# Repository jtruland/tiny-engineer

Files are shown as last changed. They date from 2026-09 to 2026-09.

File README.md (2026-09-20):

# Tiny Engineer

> Give your AI coding agent a body.

Tiny Engineer demo

Tiny Engineer is an open-source, 3D-printable desktop robot that physically acts out what an AI coding agent is doing: reading, thinking, coding, finishing tasks. It runs on an ESP32 over Wi-Fi and exposes a simple REST API, so any tool that can make an HTTP request can drive it.

**[Watch the demo](https://youtu.be/RX_QRxdXMjg) · [Build your own](#build-your-own) · [How it works](#how-it-works) · [API](docs/api.md)**

## Why?

AI coding agents increasingly spend long stretches working on their own. I wanted to see what mine was doing without staring at the IDE.

So I built a slightly ridiculous desk robot: instead of another spinner or status line, there is a tiny teammate sitting next to me, visibly reading, thinking, and typing while the agent works.

## How it works

How Tiny Engineer works

An AI agent works; an integration turns that into events; the robot’s REST API on your LAN receives them; the hardware moves and reacts.

**How it connects**

- **Cursor** — Cursor Agent → Cursor hooks → `tiny-engineer-cursor` → HTTP over Wi-Fi
- **Antigravity CLI** — Antigravity Agent → lifecycle hooks → `tiny-engineer-antigravity` → HTTP over Wi-Fi
- **Bring your own** — Claude, Codex, or any other agent → your script/plugin/app → HTTP REST

Both hit the same Tiny Engineer REST API (`/anim`). The ESP32-C3 runs that API, robot logic, and animations, then drives:

| Bus | Hardware | Role |
| --- | --- | --- |
| I2C | PCA9685 → 5× servos | Head / neck, hands / body |
| I2C | Waveshare 0.91inch OLED (SSD1306) | Status, face, info |
| I2S | MAX98357A → speaker | Audio |

Cursor is one, sample, client, not the architecture. Details: [Cursor hooks](docs/hooks.md) · [any integration](docs/integration.md) · [HTTP API](docs/api.md)

## Build your own

End-to-end path (details live in the linked docs):

New to hardware? Start with **[From Code to Circuits](docs/hardware-for-software-engineers/README.md)** — hardware and electronics for software engineers; Tiny Engineer is the worked example.

1. **Get the electronics** — [hardware inventory](docs/hardware/components.md)
2. **3D print the parts** — [printables](3d_models/README.md). Different servo size: [parametric CAD](docs/3d/parametric-design.md)
3. **Assemble the mechanics** — fit the five servos — [3D models](3d_models/README.md), [servo axes](docs/robot-movement.md)
4. **Wire the electronics** — [wiring](docs/hardware/wiring.md), [hardware overview](docs/hardware/README.md)
5. **Flash the ESP32 firmware** — [getting started → Flash](docs/getting-started.md#4-flash)
6. **Configure Wi-Fi** — [getting started → Wi-Fi](docs/getting-started.md#5-wi-fi-setup)
7. **Test the robot** — web UI + a curl — [getting started → Prove it](docs/getting-started.md#6-prove-it)
8. **Connect your coding agent** — [Cursor hooks](docs/hooks.md) or [any IDE / REST](docs/integration.md)

Full walkthrough: [docs/getting-started.md](docs/getting-started.md).

## Hardware overview

Major pieces (exact models and counts in the BOM):

| Role | Part | Qty |
| --- | --- | --- |
| Controller | Waveshare ESP32-C3-Zero | 1 |
| Servo PWM | Adafruit PCA9685 | 1 |
| Actuators | Analog micro servos — **Tower Pro SG90 recommended**; Feetech FS0307 for a compact build; PowerHD HD-1370A still supported | 5 |
| Display | [Waveshare 0.91inch OLED Module](https://www.waveshare.com/0.91inch-oled-module.htm) (SSD1306, 128×32, I2C) | 1 |
| Audio | MAX98357A + 8 Ω / 1 W speaker | 1 + 1 |
| USB / power | Adafruit 5993 USB-C breakout; **5 V / ≥2 A** supply | 1 |
| Structure | 3D-printed parts | — |

Complete inventory and limits: [docs/hardware/components.md](docs/hardware/components.md). Which servo to buy and which parts to print: [docs/3d/parametric-design.md](docs/3d/parametric-design.md).

## Quick start

Firmware is Arduino on [PlatformIO](https://platformio.org/). From the project root:

```bash
pio run                 # build
pio run -t upload       # flash firmware + LittleFS
pio device monitor      # serial (115200)
```

If servos move but audio is silent, run `pio run -t uploadfs` once.

**Wi-Fi (first boot):** join `TinyEngineer-XXXX`, open `http://192.168.4.1/config`. Wizard: servos, screen orientation, RGB LED, speaker, then a **2.4 GHz** network. OLED shows the join-AP steps.

**Web UI:** `http://tiny-engineer.local/` (or the IP on the OLED) — settings, hardware tests, animations.

**Make it move:**

```bash
curl -X POST "http://tiny-engineer.local/anim?name=ring"
```

Full route list: [docs/api.md](docs/api.md). Settings: [docs/settings.md](docs/settings.md).

## AI integrations

Anything that can `POST` over HTTP can drive the robot:

```bash
curl -X POST "http://tiny-engineer.local/anim?name=typing"
```

Useful `name` values: `typing`, `reading`, `thinking`, `ring`, `welcome`, `wakeup`, `sleep`, `attention`, `error`, `abort`, `dead`, `none`.

Cursor projects can map agent events to poses via hooks — [docs/hooks.md](docs/hooks.md). Broader patterns and examples: [docs/integration.md](docs/integration.md). Optional extra: sleep/wake when you lock or unlock a Mac — [docs/macos-lock-unlock.md](docs/macos-lock-unlock.md).

## Documentation

| Goal | Doc |
| --- | --- |
| Build end-to-end | [docs/getting-started.md](docs/getting-started.md) |
| Parts / BOM | [docs/hardware/components.md](docs/hardware/components.md) |
| Wiring / power | [docs/hardware/README.md](docs/hardware/README.md) |
| Printable parts | [3d_models/README.md](3d_models/README.md) |
| Resize CAD for another servo | [docs/3d/parametric-design.md](docs/3d/parametric-design.md) |
| Servo axes / safe ranges | [docs/robot-movement.md](docs/robot-movement.md) |
| HTTP API | [docs/api.md](docs/api.md) |
| Settings | [docs/settings.md](docs/settings.md) |
| Cursor hooks | [docs/hooks.md](docs/hooks.md) |
| Any IDE / REST | [docs/integration.md](docs/integration.md) |
| Firmware / package tests | [docs/testing.md](docs/testing.md) |
| Full index | [docs/README.md](docs/README.md) |

## Build one, break one, share it

Print it, wire it, change the CAD, swap animations, or hook up a different agent. Issues and PRs welcome — especially new integrations. See [CONTRIBUTING.md](CONTRIBUTING.md). Vulnerabilities: [SECURITY.md](SECURITY.md). Conduct: [CODE_OF_CONDUCT.md](CODE_OF_CONDUCT.md).

Tiny Engineer

## License

- **Software** (firmware, integrations, scripts, documentation) — [MIT](LICENSE)
- **Hardware designs** (CAD source and `.3mf` printables in [`3d_models/`](3d_models/); KiCad PCBs in [`hardware/`](hardware/)) — [CERN-OHL-S-2.0](3d_models/LICENSE)

See [LICENSING.md](LICENSING.md) for scope and effective date. The **Tiny Engineer** name and logo are not licensed — see [TRADEMARK.md](TRADEMARK.md).

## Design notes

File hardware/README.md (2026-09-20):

# Hardware (PCB)

KiCad PCB projects for Tiny Engineer.

Boards live under `boards/<board-name>/`. Prefer the same name for the directory and the KiCad project.

Contribution rules, KiCad version, what to commit, ERC/DRC, and PR expectations: [docs/pcb.md](../docs/pcb.md). Pre-PR checklist: [docs/pcb.md#checklist](../docs/pcb.md#checklist). Critical net checklist: [docs/pcb.md#expected-netsyml](../docs/pcb.md#expected-netsyml).

This tree is KiCad source only. Robot electrical reference (pinout, wiring, BOM) is [`docs/hardware/`](../docs/hardware/README.md). Firmware drivers are `src/hardware/`.

## License

Board sources in `boards/` are [CERN-OHL-S-2.0](LICENSE). See [NOTICE](NOTICE) for copyright, Source Location, and product notice requirements.

This README is software documentation and remains under the MIT License — [LICENSING.md](../LICENSING.md).

The **Tiny Engineer** name and logo are not licensed — [TRADEMARK.md](../TRADEMARK.md).

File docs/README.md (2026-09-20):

# Docs index

Pick a path. Depth lives in the linked pages.

| You want to… | Start here |
| --- | --- |
| **Bridge into hardware/electronics** (software engineer background) | [hardware-for-software-engineers/README.md](hardware-for-software-engineers/README.md) |
| **Build from scratch** (parts → print → wire → flash) | [getting-started.md](getting-started.md) |
| **Use with Cursor** (robot already on Wi‑Fi) | [getting-started.md](getting-started.md) → [hooks.md](hooks.md) |
| **Flash / configure** only | [getting-started.md](getting-started.md)#4-flash |
| **Wire / power detail** | [getting-started.md](getting-started.md)#3-wire-and-power → [hardware/README.md](hardware/README.md) |
| **Print / parts inventory** | [getting-started.md](getting-started.md)#2-print-and-mechanical → [../3d_models/README.md](../3d_models/README.md) |
| **Adapt CAD to a different servo** | [3d/parametric-design.md](3d/parametric-design.md) |
| **Contribute a PCB** (KiCad) | [pcb.md](pcb.md) → [`hardware/`](../hardware/README.md) |
| **HTTP API / settings** | [api.md](api.md); add a setting: [settings.md](settings.md) |
| **Any IDE / scripts** | [integration.md](integration.md) |
| **Firmware / package tests** | [testing.md](testing.md) |
| **AI coding agents (repo rules)** | [AGENTS.md](../AGENTS.md) |
| **Contribute / report a vuln** | [CONTRIBUTING.md](../CONTRIBUTING.md); [SECURITY.md](../SECURITY.md) |

Also: [robot-movement.md](robot-movement.md) (servo axes and safe ranges); optional [macos-lock-unlock.md](macos-lock-unlock.md) (sleep/wake on Mac screen lock).

**Source of truth:** pin constants in firmware (`include/pins.h`); electrical detail in `docs/hardware/`; HTTP shapes in [api.md](api.md).

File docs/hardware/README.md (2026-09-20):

# Tiny Engineer — hardware overview

Canonical hardware reference for the Tiny Engineer robot.

Firmware pin constants live in [`include/pins.h`](../../include/pins.h). Wiring topology lives in [`docs/wiring/Tiny Engineer.drawio.png`](../wiring/Tiny%20Engineer.drawio.png).

Source of truth: firmware `include/pins.h`, then this `docs/hardware/` set and `docs/wiring/`.

| Audience | Use this set for |
| --- | --- |
| Human | Assembly, wiring, power, bring-up, debugging |
| Firmware agent | Pin map, buses, voltages, servo PWM conventions, test sequence |

## Purpose

Small desktop robot with:

- 5 analog micro servos (head, neck, hands, body — [robot-movement.md](../robot-movement.md))
- I2C OLED status display
- I2S speaker for tones and WAV playback
- ESP32-C3 Wi-Fi for HTTP control and AI hooks

Firmware (`src/main.cpp`) is the robot application: Wi-Fi, settings, hardware tests, animations, and the JSON API.

## Hardware architecture

One ESP32-C3 module owns all logic. Servo PWM is offloaded to a PCA9685 so pulse generation does not depend on ESP32 timing. Audio is I2S into a class-D amp. Display and servo driver share one I2C bus.

```mermaid
flowchart TB
  USB["USB 5V / GND<br/>as drawn"]

  subgraph p5["5 V power domain"]
    ESP5["ESP32 5V"]
    PCA5["PCA9685 5V"]
    PCAVplus["PCA9685 V+"]
    MAXVIN["MAX98357A Vin"]
    SERVOS["Servo 5V"]
  end

  subgraph p33["3.3 V logic domain"]
    ESP["ESP32-C3-Zero"]
    PCA["PCA9685 VCC"]
    OLED["OLED VCC"]
  end

  USB -->|"5V"| ESP5
  USB -->|"5V"| PCA5
  USB -->|"5V"| MAXVIN
  PCA5 --> PCAVplus
  PCAVplus --> SERVOS
  ESP5 --> ESP
  ESP -->|"3V3"| PCA
  ESP -->|"3V3"| OLED
  ESP -->|"GP0 SDA / GP1 SCL"| PCA
  ESP -->|"GP0 SDA / GP1 SCL"| OLED
  ESP -->|"GP2 BCLK / GP3 LRC / GP4 DIN"| MAXVIN
  PCA -->|"PWM"| SERVOS
```

Speaker **SPK+/SPK-** are not on the PNG. See [wiring.md](wiring.md#not-on-the-drawing).

| Domain | Voltage | What lives there |
| --- | --- | --- |
| Power rail | **+5V** | USB **5V** → ESP32 **5V**, PCA9685 **5V**, MAX98357A **Vin**; PCA9685 **V+** → servo **5V** |
| Logic | **3V3** | ESP32 GPIO, PCA9685 **VCC**, OLED **VCC**, I2C, I2S |
| Ground | **GND** | Every module — common ground is mandatory |

> [!WARNING]
> Never power the servos from the ESP32 3.3 V regulator.

> [!WARNING]
> MAX98357A SPK- is not ground. Speaker connects between SPK+ and SPK- only.

## Major components

| Role | Part | Qty |
| --- | --- | --- |
| Controller | Waveshare ESP32-C3-Zero | 1 |
| Servo PWM | Adafruit PCA9685 16-channel driver | 1 |
| Actuators | Analog micro servos — **Tower Pro SG90 recommended**; Feetech FS0307 compact; PowerHD HD-1370A still supported | 5 |
| Audio amp | MAX98357A I2S class-D (mono) | 1 |
| Speaker | 8 Ω / 1 W mono | 1 |
| Display | [Waveshare 0.91inch OLED Module](https://www.waveshare.com/0.91inch-oled-module.htm) (SSD1306, 128×32, I2C) | 1 |
| Robot USB | Adafruit 5993 USB-C breakout (power + data) | 1 |

Full inventory: [components.md](components.md).

## Communication buses

| Bus | ESP32 pins | Devices |
| --- | --- | --- |
| I2C | GP0/SDA, GP1/SCL (Waveshare OLED **SCL**) | PCA9685 `0x40`, SSD1306 `0x3C` |
| I2S | GP2/BCLK, GP3/LRC, GP4/DIN | MAX98357A |
| Servo PWM | *(none on ESP32)* | PCA9685 channels 0–4 @ 50 Hz (neck 0, right hand 1, body 2, left hand 3, head 4 — see [pinout.md](pinout.md)) |
| USB | Adafruit 5993 (VBUS/GND + D+/D− → GP19/GP18) | Power, flash, serial CDC |

Details: [interfaces.md](interfaces.md), [pinout.md](pinout.md).

## Power architecture

Single nominal **+5V** supply via the Adafruit 5993. ESP32 onboard LDO makes **3V3** for logic only. PCA9685 **V+** (servos) is electrically separate from PCA9685 **VCC** (logic).

Adafruit 5993 CC resistors request **5 V / up to ~1.5 A**. Five stalled servos alone can approach that. Prefer a **5 V / ≥2 A** source with margin.

Details: [power.md](power.md).

## Documentation map

| File | Contents |
| --- | --- |
| [components.md](components.md) | Inventory, voltages, limits |
| [pinout.md](pinout.md) | GPIO map + allocation rules |
| [wiring.md](wiring.md) | Every electrical connection |
| [power.md](power.md) | Budget, brownout symptoms, single-USB policy |
| [servos.md](servos.md) | PWM, test limits, safe ranges |
| [interfaces.md](interfaces.md) | I2C / I2S / PWM / USB |
| [testing.md](testing.md) | Bring-up sequence, failures, what to check |

Existing schematic sketch (not a substitute for the tables here): [`docs/wiring/Tiny Engineer.drawio`](../wiring/Tiny%20Engineer.drawio) / [PNG](../wiring/Tiny%20Engineer.drawio.png). KiCad PCB sources (when added) live in [`hardware/boards/`](../../hardware/README.md); contribution rules: [`docs/pcb.md`](../pcb.md). Until a board is merged, the wiring tables here remain the electrical source of truth.

## Source-of-truth order

1. Repository firmware / `include/pins.h`
2. This `docs/hardware/` set and `docs/wiring/`
3. Component datasheets

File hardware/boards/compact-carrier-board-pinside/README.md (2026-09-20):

# compact-carrier-board-pinside

**The pin-side (mirrored) revision of
[`compact-carrier-board`](../compact-carrier-board/README.md), kept because it is
what the boards in transit physically are.** Do not order it unless you
specifically want the build described below.

- **Status:** frozen — archival variant, not developed further
- **Artwork:** byte-identical to `compact-carrier-board` as of commit `ddeb0d0`
  (md5 `26995498ccf56c28db661f4333d1f64c` — checksum of a public board file, secret-scan:allow), i.e. the
  `carrier-fab-v3-replacement_Y5` upload JLCPCB produced and shipped
- **KiCad:** 10

## What is different

Its socket pad map is the ESP32-C3-Zero seen from the **pin side**: `J_ESP1`
(5V, GND, 3V3, GPIO0-GPIO5) sits on the OUTER row nearest the slot edge and
`J_ESP2` (GPIO21-GPIO6, D+/D- on pins 16/15) on the inner row. The corrected
board has those two rows the other way round.

A pin-side map is the correct drawing only for a socket on the **opposite
face** from the one being drawn — which is why this board mates only when
built the following way.

## How to build it

1. Solder both Kinghelm KH-2.54FH-1X9P-H3.5 female strips to the **pour face**
   (B.Cu — the GND-fill side, the one with no silkscreen).
2. Run the board with that face **up**. From the pour face you see the mirror
   of the F.Cu artwork, which is the module's component-side map, so a
   component-side-up module mates correctly.
3. Mark pin 1 before assembly — the silkscreen ends up underneath. Pin 1 (5V)
   is the square pad, at the corner of the socket array that the wide 5V trace
   runs to, and that trace is visible on the pour face.
4. Plugged in 180° out, 5V lands on GPIO5.

## What that build costs

- The module's own USB-C overhangs the long edge facing the **opposite wall**
  from the corrected board's intent. Unused either way — the Adafruit 5993
  jack carries power and CDC, see
  [`docs/hardware/interfaces.md`](../../../docs/hardware/interfaces.md).
- Silkscreen faces down, so the reference designators are unreadable after
  assembly, and this artwork has no pin-name silk to lose in the first place.
- The wire-end connector positions mirror left-right, so the runs to the
  PCA9685 / OLED / amp swap sides relative to the corrected board.
- The corrected board's routing fixes are absent here, measured on this file:
  9mm of the 5V net sits at 0.600mm against its own ≈0.78mm IPC-2221 target
  (total length 83.901mm), and the worst track-to-pad clearance is 0.270mm.

## Choosing between the two

| | `compact-carrier-board` | this variant |
| --- | --- | --- |
| Headers soldered to | silk face (F.Cu) | pour face (B.Cu) |
| Face up in the desk | silk | pour |
| Module USB-C overhangs | the 5V-bus long edge | the opposite long edge |
| Pin names on silk | yes | no |
| 5V net | 44.939mm, all 1.000mm | 83.901mm, 9mm of it 0.600mm |
| Worst track-to-pad | 0.420mm | 0.270mm |
| Use it when | ordering new boards | you have the in-transit batch in hand |

`kicad-cli pcb drc --severity-all` on this file reports 0 violations and 0
unconnected items. It is electrically sound; it is the row assignment that is
inverted, and DRC cannot see that — only handedness can.

## License

Board sources in `boards/` are [CERN-OHL-S-2.0](../../LICENSE). See
[NOTICE](../../NOTICE) for copyright, Source Location, and product notice
requirements.

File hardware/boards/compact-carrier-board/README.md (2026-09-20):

# compact-carrier-board

Small distribution PCB that sits under the ESP32-C3-Zero where it mounts through
the desk's ESP slot, fanning its I2C/I2S/power pins out to the PCA9685, OLED,
MAX98357A amp, and servo power — instead of point-to-point wiring.

- **Status:** in review
- **KiCad:** 10
- **Interfaces:** ESP32-C3-Zero 2×9 socket, `J_PWR` (5V/GND + external USB
  D+/D-), `J_SERVO`, `J_I2C_OLED`, `J_I2C_PCA`, `J_I2S`
- **Assumptions:** sized against the desk generated with the **PowerHD
  HD-1370A** servo preset (`servos.json`) — the SG90 and FS0307 presets
  produce different desk dimensions per the parametric design docs, and this
  board's fit has **not** been verified against either of them. Re-check the
  ESP slot dimensions in your own exported desk model before relying on this
  outline if you're on a different preset. See `docs/hardware/interfaces.md`
  for the canonical net map (5V/3.3V domains, GP0-GP4 assignments); this
  board implements that map in copper.
- **Built:** the `carrier-fab-v3-replacement_Y5` upload was produced and
  shipped by JLCPCB (not yet received). That batch carries the **mirrored
  socket map this revision fixes** — see "Mirrored socket map (boards in
  transit)" below for the assembly workaround. Its drilling is fine: the Y5
  drill export is a single 0.9mm tool over all 37 holes and JLC's own CAM
  layer a single aperture, so the 7-undersized-hole defect of the earlier
  `_Y3` upload never reached a physical board.

## Files

- `compact-carrier-board.kicad_pcb` — KiCad 10 board source
- `compact-carrier-board.kicad_pro` — KiCad 10 project file (no `.kicad_sch`
  — this board has no schematic, laid out directly from footprints)
- `carrier-board-render.png` — 3D top render, regenerated with
  `kicad-cli pcb render --side top` after the row swap and silk additions

Gerbers, drill, BOM, and CPL are generated outputs, not source — regenerate
them from `compact-carrier-board.kicad_pcb` when ordering rather than
relying on a committed copy. `J_ESP1`/`J_ESP2` carry real `Value`/`LCSC`
fields and each footprint has a real origin at its own center, so
`kicad-cli pcb export pos` produces correct positions directly (verified:
`(13.00, -16.89)` / `(13.00, -1.65)`) — no manual patching. `J_PWR`,
`J_SERVO`, `J_I2C_OLED`, `J_I2C_PCA`, and `J_I2S` are flagged
`exclude_from_bom`/`exclude_from_pos_files` so they never appear in either
export. There's no `.kicad_sch`, so `kicad-cli` has no BOM-export
subcommand for this board (that's a schematic-only feature) — a BOM script
or fab-tool plugin reading the `.kicad_pcb`'s footprint properties directly
now gets correct `Value`/`LCSC` without hand-derivation.

## Assembly: only the ESP header strips are populated parts

`J_PWR`, `J_SERVO`, `J_I2C_OLED`, `J_I2C_PCA`, and `J_I2S` are bare
through-holes for direct wire connections, not connector footprints to
populate — excluded from BOM/CPL at the footprint level (see above).

`J_ESP1`/`J_ESP2` are the one real part: **Kinghelm KH-2.54FH-1X9P-H3.5**
(LCSC/JLCPCB `C55778388`), a 2.54mm 1×9 THT female header. There's no 2×9 part
— the
ESP32-C3-Zero's socket needs **two** of these strips, one per row. The board
models this as two separate footprint objects, **`J_ESP1`** (the inner row,
nearer the wire end: 5V/GND/3V3/GPIO0-5) and **`J_ESP2`** (the outer row,
nearest the slot edge: GPIO21-GPIO6), each a real
9-pad object with its own designator — not one 2×9 footprint with a
quantity hint in prose. JLCPCB's assembly tooling (and most BOM tooling)
determines quantity by counting designators, not by parsing Comment text, so
a generated BOM lists both on one row as `"J_ESP1,J_ESP2"` (identical part,
JLC's own convention for grouping identical components) — that reads as qty
2 unambiguously.

A generated CPL has one row per designator, `J_ESP1` and `J_ESP2`, each at
its own row's real center — (13.00, 16.89) and (13.00, 1.65) in the board's
own coordinates — read directly by `kicad-cli pcb export pos` from each
footprint's own origin, no hand-derivation needed.

## Why this shape

Measured directly from an exported desk part (not estimated): the ESP mounting
slot is 25.0 × 18.5mm, and three of its four sides sit only 3.0–3.6mm from
full-height enclosure walls — too tight for any connector housing. Only the
front is open. That forced the layout:

- **26 × 44mm**, 2-layer.
- Back 18.5mm: 2×9 female socket for the ESP32-C3-Zero (2.54mm pitch,
  15.24mm row spacing — Waveshare's documented spec for the Zero board family,
  confirmed within 0.04mm of a direct caliper measurement).
- Front zone: `J_PWR` (now 4-pin — 5V/GND plus the external USB D+/D-, see
  below), `J_SERVO` (5V direct to PCA9685 V+, bypassing the ESP's own 3.3V
  regulator), `J_I2C_OLED`, `J_I2C_PCA` (separate connectors, bus shared via
  on-board copper — no external splitter cable), `J_I2S` (own on-board 5V
  feed for the amp).
- Everything routes fully on-board; nothing needs an off-board jumper.

## Pinout (rows stated in the frame that decides them)

Row placement is the part that is easy to get backwards, so name the rule:
**the pad map, seen from the face the module plugs into, has to be the
module's component-side view.** A pin-side view is the correct drawing only
for a socket on the *opposite* face — that inversion is exactly what went
wrong in the shipped batch (below).

Hold the C3-Zero component side up with its USB-C over this board's 5V-bus
edge (the long edge the 5V trace hugs). Then:

- **Outer row** — `J_ESP2`, nearest the slot edge (y=14.15):
  `GPIO21, GPIO20, GPIO19, GPIO18, GPIO10, GPIO9, GPIO8, GPIO7, GPIO6`.
  Mechanical/no-net support **except GP19 and GP18**, the native USB pair —
  see USB below.
- **Inner row** — `J_ESP1`, nearer the wire end (y=29.39):
  `5V, GND, 3V3, GPIO0(SDA), GPIO1(SCL), GPIO2(BCLK), GPIO3(LRCLK), GPIO4(DIN), GPIO5`

Pins 1 and 18 land at the 5V-bus edge in both rows, and that is what fixes
the module's USB-C to that edge. Traversing 1 to 18 reads counter-clockwise
from above, matching Waveshare's own pinout art (1-9 down the left column,
10-18 up the right, USB-C at the top).

## USB pass-through (external jack, not the C3-Zero's own USB-C)

Per `docs/hardware/interfaces.md`: the robot's single external USB-C (Adafruit
5993) carries both power and the ESP32's native USB D+/D- lines, so flashing
and serial CDC work through the panel-mount jack once the desk is sealed —
the C3-Zero's own onboard USB-C is left unused. No ESD or series-resistor
circuitry is specified for this link; it's a direct connection.

| `J_PWR` pin | Net | Goes to |
| --- | --- | --- |
| 1 | GND | common ground |
| 2 | D+ | ESP32 **GPIO19** (outer-row pad, native USB DP) |
| 3 | D− | ESP32 **GPIO18** (outer-row pad, native USB DM) |
| 4 | 5V | ESP32 5V rail, PCA9685 V+ (via `J_SERVO`), MAX98357A |

D+/D- run down the same 2.54mm grid columns as their own pads (x=20.42 and
22.96), which sits half a pitch off `J_I2C_OLED`/`J_I2C_PCA`'s grid, so they
never cross those connectors' pads on the way past. Since the row swap they
also pass the inner row, where the 3V3 and SDA holes occupy those two
columns, so each line takes one short lateral jog into the adjacent lane
(1.27mm off-axis, 0.42mm to the nearest pad edge) and returns — still F.Cu,
no vias. Each line measures 36.088mm and the two are exactly length-matched;
that is 16mm longer than before the swap, which is electrically unremarkable
at full-speed 12 Mbps.

## Mirrored socket map (boards in transit)

That artwork is preserved as its own board, [`compact-carrier-board-pinside`](../compact-carrier-board-pinside/README.md),
so the build the in-transit batch needs stays orderable and documented rather than
living only in this section's prose.

**The shipped boards (`carrier-fab-v3-replacement_Y5`) have the two socket
rows the wrong way round.** Their pad map is the C3-Zero seen from its *pin
side*, which is the correct drawing only for a socket on the opposite face;
as fabricated, a component-side-up module does not mate.

Caught by handedness, which no rotation can change: on the module
(component side, USB-C up) pins 1-9 run DOWN the left column and 10-18 UP
the right, so 1 to 18 is counter-clockwise; on those boards `J_ESP1` 1 to 9
runs left-to-right along the outer row and `J_ESP2` 10 to 18 right-to-left
along the inner row, i.e. clockwise.

**This revision fixes the source** — rows swapped in copper, nothing moved
mechanically. **For the boards in transit, fix it at assembly:** solder both
female strips to the **pour face** (B.Cu) and run that face up. From the
pour face you see the mirror of the F.Cu artwork, which is the
component-side map, so the module mates. What that build costs: the module's
own USB-C ends up over the long edge facing the opposite wall from this
revision's intent (unused either way — the Adafruit 5993 jack carries power
and CDC), the silkscreen ends up underneath so mark pin 1 before assembly,
and the wire-end connector positions mirror left-right, so the runs to the
PCA9685 / OLED / amp swap sides.

## Fab notes

- `kicad-cli pcb drc --severity-all` (KiCad 10.0.6, run *without*
  `--refill-zones` so it judges the on-disk fill) reports **0 violations and
  0 unconnected items** — and that statement now means something. The
  project's DRC floors used to be `min_clearance` 0.0, `min_silk_clearance`
  0.0, `min_text_height` 0.8 and `min_text_thickness` 0.08, so DRC could not
  have failed on clearance, silk overlap or undersized text however bad they
  got. They are now 0.2 / 0.15 / 1.0 / 0.15, matching JLCPCB's floors and
  its standard-font minimum. Schematic parity is not checked and cannot be —
  there is no `.kicad_sch` for this board, and `--schematic-parity` answers
  "Schematic parity tests require a fully annotated schematic".
- **Every pad on the board is named on silk.** The socket rows carry
  `GP21`-`GP6` (outer) and `5V, GND, 3V3, GP0`-`GP5` (inner) with a `USB`
  arrow pointing at the 5V-bus edge; each wire-end connector carries its own
  pin names (`3V3/SDA/SCL/GND` on both I2C headers, `5V/BCLK/LRC/DIN/GND` on
  `J_I2S`, `GND/D+/D-/5V` on `J_PWR`, `5V/GND` on `J_SERVO`). 48 silk items,
  all 1.0mm height / 0.15mm stroke. Placement is checked geometrically, not
  by DRC — 0 silk-to-silk overlaps, 0.421mm minimum silk-to-pad, 0.383mm
  minimum silk-to-edge. Before this the board carried nothing but seven
  reference designators, which is why a mirrored pad map was invisible both
  in the render and on the bare board.
- The seven reference designators were 0.8mm high with a 0.12mm stroke,
  under JLCPCB's standard-font minimum and passing DRC only because
  `min_text_thickness` was 0.08. All seven are now 1.0mm / 0.15mm.
  `J_I2C_PCA`, `J_PWR` and `J_SERVO` moved to clear the new pin-name bands,
  and every label is re-checked against the 0.30mm edge margin — three of
  them sit at exactly that margin, so the larger text boxes were nudged back
  inside rather than allowed to overhang.
- GND pour clearance raised 0.20 → 0.25mm — the zone's local clearance and
  the Default netclass together — and refilled. At 0.20 the fill sat at
  exactly JLCPCB's floor with nothing left for their etch tolerance; the
  nearest track-based constraint is 0.42mm, so the extra 0.05mm costs no
  geometry.
- 4 reference designators (`J_ESP1`, `J_ESP2`, `J_I2C_OLED`, `J_I2C_PCA`)
  were printing 0.2–0.6mm past the board's left edge — visually confirmed,
  not just a DRC technicality. Each footprint's own text bounding box (not
  an estimate) was used to shift the label right just enough to sit at a
  0.3mm margin from the edge; the render below reflects the fix.
- GND zone (B.Cu) outline is inset 0.5mm from the board edge, not 1mm as in
  earlier revisions — the 1mm inset put pads near the top edge (e.g. `J_ESP1`
  pin 2, GND) close enough to the zone's own boundary that a fresh zone
  refill could fail to route a thermal-relief connection to them, especially
  after the `J_ESP2` drill fix changed nearby pad geometry. Swept the inset
  from 1.0mm down to 0.3mm in 8 steps against the drill-fixed board, each
  with a fresh `kicad-cli pcb drc --refill-zones`: 1.0mm and 0.8mm both
  reproducibly fail with 1 unconnected pad; every value from 0.6mm down to
  0.3mm passes with 0. 0.5mm sits in the middle of that verified-safe range
  — well clear of the failure boundary and with real margin above JLCPCB's
  ~0.2–0.3mm copper-to-edge floor.
- Tightest feature: 0.15mm copper (GND pour minimum thickness). Comfortably
  inside JLCPCB's 0.127mm floor; sits exactly at PCBWave's 0.15mm floor (their
  recommended safe minimum is 0.20mm) — check their DFM report before ordering
  if using PCBWave.
- Connectors are plain 2.54mm through-hole pads (pin headers + jumpers), not
  JST — real JST-PH footprint dimensions weren't verified at design time.
- 5V trace sized per IPC-2221 (2A, 1oz copper, 10°C rise → ≈0.78mm minimum).
  The whole net is now 1.0mm over its 44.9mm length, with **no pinch points
  left**: the row swap moved the 5V pad off the outer row onto the inner one,
  15.24mm closer to its loads, which removed the squeeze past the mechanical
  pad row that previously forced two short 0.6mm sections.
  Any track change requires refilling the GND zone, and the refill must be
  done via KiCad itself (GUI Fill All Zones + save, or the
  `pcbnew.ZONE_FILLER` Python API) and re-verified with `kicad-cli pcb drc`
  run *without* `--refill-zones` — that flag only recomputes the fill
  in-memory for the check, it does not persist to the file, so a stale
  on-disk fill can pass DRC while still being wrong in the Gerbers. This bit
  us once already in this revision's history.

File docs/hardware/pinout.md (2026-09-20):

# Pinout

Source of truth: [`include/pins.h`](../../include/pins.h). This file must match that header.

## Assigned ESP32-C3-Zero GPIO

| Function | ESP32-C3-Zero GPIO | Constant | Goes to |
| --- | --- | --- | --- |
| I2C SDA | **GPIO0** (diagram **GP0**) | `I2C_SDA` | PCA9685 SDA, OLED SDA |
| I2C SCL | **GPIO1** (diagram **GP1**) | `I2C_SCL` | PCA9685 SCL, Waveshare OLED **SCL** |
| I2S BCLK | **GPIO2** (diagram **GP2**) | `I2S_BCLK` | MAX98357A BCLK |
| I2S LRCLK / WS | **GPIO3** (diagram **GP3**) | `I2S_LRC` | MAX98357A **LRC** |
| I2S DATA OUT | **GPIO4** (diagram **GP4**) | `I2S_DIN` | MAX98357A DIN |
| PCA9685 OE (optional) | **GPIO5** (diagram **GP5**) | `PCA9685_OE_PIN` | PCA9685 **OE** when `PCA9685_OE_WIRED` |
| Built-in WS2812 RGB | **GPIO10** | `RGB_LED_PIN` | onboard LED only |

Logic level: **3.3 V**.

## Reserved / unavailable

| GPIO | Status | Reason |
| --- | --- | --- |
| GPIO9 | **Reserved** | BOOT button / strapping. Do not pick casually for peripherals |
| GPIO10 | **Occupied** | Onboard WS2812 |
| GPIO12–GPIO17 | **Unavailable** | Stacked flash, not brought out |
| GPIO18 | **Reserved** | Native USB D− (via Adafruit 5993 D−) |
| GPIO19 | **Reserved** | Native USB D+ (via Adafruit 5993 D+) |

## Free / default-function pads

| GPIO | Status | Notes |
| --- | --- | --- |
| GPIO5 | **Optional** | PCA9685 **OE** when wired; set `PCA9685_OE_WIRED = true` in `pins.h` |
| GPIO6 | Free | Unused |
| GPIO7 | Free | Unused |
| GPIO8 | Free | Unused |
| GPIO20 | Default UART0 RX | Silkscreen RX. Free for other use only if USB CDC remains the console (`ARDUINO_USB_CDC_ON_BOOT=1`) |
| GPIO21 | Default UART0 TX | Silkscreen TX. Same caveat as GPIO20 |

Power pads (not GPIO): **5V**, **GND**, **3V3**.

## PCA9685 channels (not ESP32 GPIO)

| PCA9685 channel | Firmware constant | Index | Mechanism |
| --- | --- | --- | --- |
| 0 | `SERVO_NECK` | 1 | Neck yaw |
| 1 | `SERVO_HAND_RIGHT` | 3 | Right hand |
| 2 | `SERVO_BODY` | 4 | Body / torso |
| 3 | `SERVO_HAND_LEFT` | 2 | Left hand |
| 4 | `SERVO_HEAD` | 0 | Head pitch — [robot-movement.md](../robot-movement.md) |
| 5–15 | unused | — | available |

⚠️ **Channel ≠ index.** The `SERVO_*` constants are array indices into
`SERVO_SPECS`, `g_servos[]` and the saved min/max blob in NVS; the PCA9685
output is the `channel` field of `SERVO_SPECS`, and it is the only one that
reaches `pwm.setPWM()`. `POST /test/servo?index=N` takes the **index**, so it
no longer matches the channel number. Re-plugging a servo means editing
`channel`, never the constants.

## Other constants in `pins.h` (not pins)

| Constant | Value | Meaning |
| --- | --- | --- |
| `SAMPLE_RATE` | 44100 | I2S sample rate |
| `PCA9685_ADDRESS` | `0x40` | I2C |
| `OLED_ADDRESS` | `0x3C` | I2C |
| `OLED_WIDTH` / `OLED_HEIGHT` | 128 / 32 | Display |
| `SERVO_MIN_US` / `SERVO_MAX_US` | 800 / 2200 | Electrical PWM span |
| `SERVO_BOOT_SPEED_DEG_S` | 35 | Boot centering / sleep-pose rate (deg/s) |
| `PCA9685_OE_WIRED` | `false` | Set `true` after wiring GP5 → PCA9685 OE |

## Pin allocation rules

New hardware **must not** pick pins ad-hoc.

1. Choose a pad from the **Free** table above, or a documented unused PCA9685 channel.
2. Do not use **Reserved** or **Unavailable** pins.
3. Update **both**:
   - [`include/pins.h`](../../include/pins.h)
   - this `pinout.md`
4. Update [wiring.md](wiring.md) and [interfaces.md](interfaces.md) in the same change.
5. Stay in the **3.3 V** GPIO domain. Level-shift if a new device is 5 V-only.
6. I2C devices need a unique address on the shared GPIO0/GPIO1 bus.
7. After the edit, grep the repo for old GPIO numbers so comments and tests stay consistent.

Related: [wiring.md](wiring.md), [interfaces.md](interfaces.md).

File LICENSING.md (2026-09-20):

# Licensing

This repository contains both software and hardware design files. They are licensed separately.

## Software — MIT License

The following are licensed under the [MIT License](LICENSE):

| Path | Contents |
| --- | --- |
| `src/`, `include/`, `lib/`, `test/` | Firmware |
| `packages/`, `scripts/`, `package.json` | Integrations and tooling |
| `data/`, `assets/` | Firmware filesystem assets |
| `docs/` | Documentation (including wiring diagrams and hardware guides) |
| `.cursor/` | Cursor hook configuration |
| `platformio.ini`, `partitions.csv` | Build configuration |
| All other repository files | Unless explicitly listed under hardware below |

## Hardware designs — CERN-OHL-S-2.0

Mechanical CAD, printable manufacturing outputs, and PCB sources are licensed under the [CERN Open Hardware Licence Version 2 — Strongly Reciprocal (CERN-OHL-S-2.0)](3d_models/LICENSE):

| Path | Contents |
| --- | --- |
| `3d_models/cad/` | Source CAD (`.f3d`) |
| `3d_models/parts/` | Printable part exports (`.3mf`) |
| `hardware/boards/` | KiCad PCB projects |

Commercial use of these hardware designs is allowed. If you modify and distribute Products based on these designs, the reciprocal provisions of CERN-OHL-S-2.0 require that you make the corresponding Complete Source available under the same license. See [3d_models/LICENSE](3d_models/LICENSE), [3d_models/NOTICE](3d_models/NOTICE), [hardware/LICENSE](hardware/LICENSE), and [hardware/NOTICE](hardware/NOTICE) for copyright, warranty disclaimer, and Source Location details.

Documentation in `3d_models/README.md` and `hardware/README.md` is software documentation and remains under the MIT License.

### Source Location

Canonical mechanical design source:

`https://github.com/jamro/tiny-engineer/tree/main/3d_models`

Canonical PCB design source:

`https://github.com/jamro/tiny-engineer/tree/main/hardware`

When distributing a specific revision, link to the corresponding tagged release or commit (for example, `https://github.com/jamro/tiny-engineer/tree/v0.1.0/3d_models`).

## Trademarks

The **Tiny Engineer** name and logo are **not** licensed under either MIT or CERN-OHL-S-2.0. See [TRADEMARK.md](TRADEMARK.md).

## Machine-readable license mapping

Per-path SPDX annotations are in [REUSE.toml](REUSE.toml).

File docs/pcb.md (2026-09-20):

# Hardware contribution guidelines (PCB)

Baseline for contributing KiCad PCB designs. Goal: boards that are easy to understand, review, reproduce, and maintain — without extra process yet.

Before opening a PR, run the [checklist](#checklist).

Workflow and automated validation are still evolving. A reference board and CI pipeline are in progress and will be used to validate these rules.

KiCad sources live in [`hardware/boards/`](../hardware/README.md). Robot electrical reference (pinout, wiring, BOM) stays in [`docs/hardware/`](hardware/README.md). Firmware drivers stay in `src/hardware/`.

Legal: board sources are CERN-OHL-S-2.0 — [LICENSING.md](../LICENSING.md), [`hardware/LICENSE`](../hardware/LICENSE), [`hardware/NOTICE`](../hardware/NOTICE). New board paths need a matching `[[annotations]]` block in [REUSE.toml](../REUSE.toml).

## Project structure

Each PCB is a separate, self-contained KiCad project:

`hardware/boards/<board-name>/`

Keep the directory name and KiCad project name the same.

Example:

```
hardware/
  boards/
    controller/
      controller.kicad_pro
      controller.kicad_sch
      controller.kicad_pcb
      expected-nets.yml
      README.md
      libraries/
        symbols/
        footprints/
        3d/
```

Do not introduce repository-wide shared KiCad libraries at this stage.

If a board needs custom symbols, footprints, or 3D models, keep them inside that board's directory. Duplication between projects is preferred over shared dependencies too early.

Shared libraries may come later if reuse across boards becomes significant.

## KiCad version

Use **KiCad 10** (current project major). Point releases (10.0.x) are fine.

Do not upgrade a board to a newer KiCad major as part of an unrelated change. Major upgrades are a dedicated, intentional change.

Existing in-progress boards may stay on the major they were started with until a dedicated upgrade.

## Libraries and portability

A contributed board must clone and open on another computer without files from the contributor's local environment.

Store custom project assets inside the board directory.

Use project-relative paths where needed, preferably `${KIPRJMOD}`.

Do not commit absolute local paths such as:

- `C:\Users\...`
- `/Users/...`
- `/home/...`

Standard symbols and footprints shipped with KiCad do not need to be copied into the project.

## Files to commit

Commit the source files required to edit and reproduce the design, including where applicable:

- `.kicad_pro`
- `.kicad_sch`
- `.kicad_pcb`
- `.kicad_dru`
- project-specific symbol libraries
- project-specific footprint libraries
- required 3D models
- `sym-lib-table`
- `fp-lib-table`
- board documentation (`README.md`)
- `expected-nets.yml` (critical net memberships for review — see [below](#expected-netsyml))

Do not commit temporary, local, backup, or generated files such as:

- `.history/`
- `*-backups/`
- `_autosave-*`
- `*.kicad_prl`
- `fp-info-cache`
- `~*.lck`
- generated Gerber files
- generated drill files
- generated PDFs
- generated BOM or pick-and-place files

Manufacturing outputs should be generated from the source design when they are actually needed.

## Schematic and PCB quality

Before submitting or updating a hardware pull request:

- Run Electrical Rules Check (ERC).
- Run Design Rules Check (DRC).
- Review all reported violations.
- Do not suppress ERC or DRC violations only to make the checks pass.
- Any intentional exception should have a clear reason.

The project should not introduce unexplained ERC or DRC errors.

Automated ERC and DRC via GitHub Actions is planned and is being tested on a reference board. It is not required yet.

## expected-nets.yml

Committed checklist of **critical** net → pin memberships for human/AI review. Not a full netlist dump.

- **Path:** `hardware/boards/<board-name>/expected-nets.yml`
- **Check:** `kicad-cli sch export netlist`, then compare to this file. No `kicad-cli` → say so and skip connectivity claims ([AGENTS.md](../AGENTS.md)).
- **Do not** infer nets from `.kicad_sch` / `.kicad_pcb` coordinates or geometry.
- **Update** when you intentionally change listed nets or pins. Keep the list to power and important buses (I2C, I2S, USB, …), not every net.

Minimal shape (pin tokens = KiCad netlist `RefDes.PinName`):

```yaml
nets:
  "+5V":
    - ESP1.5V
    - PCA1.V+
  GND:
    - ESP1.GND
    - PCA1.GND
```

Required for new or updated boards when claiming connectivity in a PR.

## Board README

Each board gets a short `README.md`. At minimum:

- what the board does
- current development status
- main components or interfaces
- important design assumptions
- whether this revision has been physically manufactured and tested

Keep it practical. Do not duplicate what is already obvious from the schematic.

Skeleton:

```markdown
# <board-name>

<one-line purpose>

- **Status:** draft / in review / manufactured / tested
- **KiCad:** 10
- **Interfaces:** <connectors, buses, power>
- **Assumptions:** <voltage, stack-up, mechanical fit, …>
- **Built:** not manufactured | manufactured, not tested | manufactured and tested
```

## Pull requests

Keep hardware pull requests focused on one logical change where reasonably possible.

The pull request should state:

- what changed and why
- whether the schematic, PCB layout, and/or symbols or footprints changed
- whether ERC and DRC were reviewed
- whether `expected-nets.yml` was updated
- whether the board has been physically tested

A design that passed ERC and DRC is not automatically physically validated. Say clearly whether it was only reviewed in KiCad or actually manufactured and tested.

Commit and PR title: `type(pcb): summary` — [CONTRIBUTING.md](../CONTRIBUTING.md). PCB-only `feat(pcb)` / `fix(pcb)` versions the hardware design, not the npm packages.

## Manufacturing files

Gerbers and other manufacturing outputs are not source files. Do not normally commit them.

Manufacturer requirements vary. Contributors are not required to attach production files to every hardware PR.

When manufacturing a board:

1. Generate the required outputs from the KiCad source.
2. Follow the selected manufacturer's requirements.
3. Inspect the generated files before ordering.
4. Verify the result in the manufacturer's Gerber viewer where available.

A more standardized manufacturing and release workflow may come later, after the process has been validated on real boards.

## Checklist

Use this before opening or updating a PCB pull request. Details are in the sections above.

**Structure and version**

- [ ] Board lives in `hardware/boards/<board-name>/`
- [ ] Directory name matches the KiCad project name
- [ ] KiCad **10** (no drive-by major upgrade)
- [ ] Custom symbols, footprints, and 3D models (if any) are inside that board directory

**Portability and files**

- [ ] Project opens after a clean clone (no files from a local KiCad install)
- [ ] Paths are project-relative (`${KIPRJMOD}`); no absolute `C:\Users\…`, `/Users/…`, or `/home/…`
- [ ] Source committed: `.kicad_pro`, `.kicad_sch`, `.kicad_pcb`, `expected-nets.yml`, plus `.kicad_dru`, lib tables, and custom libs when used
- [ ] No `.history/`, `*-backups/`, `_autosave-*`, `*.kicad_prl`, `fp-info-cache`, or lock files
- [ ] No generated Gerbers, drill files, PDFs, BOM, or pick-and-place outputs

**Quality and docs**

- [ ] ERC run; violations reviewed
- [ ] DRC run; violations reviewed
- [ ] No suppressions used only to make checks pass; any intentional exception has a reason
- [ ] `expected-nets.yml` present and matches current netlist for listed nets
- [ ] Board `README.md` covers purpose, status, interfaces, assumptions, and whether this revision was manufactured and tested
- [ ] New board path has a matching `[[annotations]]` block in `REUSE.toml` (CERN-OHL-S-2.0)

**Pull request**

- [ ] Title is `type(pcb): summary`
- [ ] PR states what changed and why
- [ ] PR states whether schematic, PCB layout, and/or symbols or footprints changed
- [ ] PR states ERC/DRC result
- [ ] PR states whether `expected-nets.yml` was updated
- [ ] PR states physical status: KiCad review only / manufactured / manufactured and tested

Existing in-progress PRs: align where reasonably possible. Do not redesign solely to satisfy this list.

## Current baseline vs future direction

The requirements above are the current contribution baseline.

Not standardized yet (to be evaluated on the reference board):

- automated KiCad ERC and DRC in GitHub Actions
- exact multi-board CI structure
- manufacturing jobsets
- automated manufacturing artifacts
- release and prerelease manufacturing packages
- shared KiCad libraries
- automated PCB renders or visual diffs
- manufacturer-specific output configurations

Once the reference implementation is validated, this page will be updated. Stable parts of the workflow may become required for new hardware contributions.

Keep the workflow reproducible and safe. Avoid complexity until it solves a real problem.

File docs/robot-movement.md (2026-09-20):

# Robot layout and movement

The robot sits in a chair beside a desk. A miniature laptop and a service bell sit on the desk in front of it. Five micro servos drive the pose; limits and channel IDs are in [`include/servos.h`](../include/servos.h).

| Index | PCA channel | Servo | Motion | At `min` | At `max` | Safe range (°) |
|---:|---:|---|---|---|---|---|
| 0 | 4 | **Head** | Face up / down (pitch) | down | up | 50 – 130 |
| 1 | 0 | **Neck** | Head left / right (yaw) | left | right | 30 – 150 |
| 2 | 3 | **Left hand** | Hand up / down | down | up | 40 – 110 |
| 3 | 1 | **Right hand** | Hand up / down (inverted scale) | up | down | 60 – 130 |
| 4 | 2 | **Body** | Whole torso left / right | right | left | 36 – 89 |

⚠️ **Index is not the PCA9685 channel** on this build — the harnesses were attached without tracking which output went where, so `SERVO_SPECS[].channel` carries the real mapping. `POST /test/servo?index=N` takes the index.

⚠️ **The neck's direction is reversed from stock.** Its horn was remounted 180° to bring the head forward at 90°, which flips which way increasing angle turns it — hence `min` = left here where stock had `min` = right. Verify against an animation before trusting it.

Ranges are this robot's measured calibration, not the stock figures. Those values are **defaults**. After setup AP calibration they are stored in NVS. Factory reset keeps the saved ranges. Retune them in the setup wizard when AP mode is open.

Animations author poses in **−1..1** relative to each joint’s saved min/max (`−1` = min, `0` = mid, `+1` = max). Horn offset after assembly is absorbed by calibration; firmware maps those poses with `servoNormToDeg`. Right-hand rest is still electrical min (`−1`); left-hand rest is electrical max (`+1`).

**Head** tilts the face toward or away from the laptop. **Neck** pans the head side to side. **Hands** lift and lower over the keyboard; the forearms have no elbow servo — the arm linkage is fixed, so only the hand joint moves. **Left** and **right** hand servos use opposite scales: on the left, higher angle is up; on the right, higher angle is down (rest pose for typing is left at `max`, right at `min`). **Body** rotates the whole upper body in the chair while the base stays put.

Command a single joint for bench checks:

```bash
curl -X POST "http://tiny-engineer.local/test/servo?index=0&angle=90"
```

Use angles inside the saved safe range on the assembled robot. During setup AP, `POST /setup/servo` can command the full 0–180° electrical range so you can find those limits.

Related: [servos.md](hardware/servos.md) (PWM and electrical limits), [api.md](api.md) (`/test/servo`, `/anim`).

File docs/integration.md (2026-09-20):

# Integrating Tiny Engineer

Tiny Engineer is a Wi-Fi desk robot. Drive it from any tool that can make HTTP requests, or use one of the dedicated helpers (Cursor, Antigravity, Claude Code) that map agent hook events to poses.

Robot must be on the same network. Base URL: `http://tiny-engineer.local` (or the IP shown on the OLED). Full HTTP reference: [`api.md`](api.md).

Four integration paths:

| Path | Best for | How |
|---|---|---|
| **REST API** | Any AI IDE, script, CI, custom agent | `POST /anim?name=…` |
| **Cursor CLI** | Cursor project hooks | `npx` → `tiny-engineer-cursor` |
| **Antigravity CLI** | Antigravity CLI lifecycle hooks | `tiny-engineer-antigravity` |
| **Claude Code CLI** | Claude Code project hooks | `tiny-engineer-claude-code` |

```mermaid
flowchart TB
  subgraph anyIde [Any AI IDE or script]
    HookOrScript[Agent event or your code]
    HookOrScript --> Post["POST /anim?name=typing|reading|…"]
  end
  subgraph cursorPath [Cursor]
    CursorHook[Cursor hooks.json]
    CursorHook --> Npx["npx tiny-engineer-cursor"]
    Npx --> Post
  end
  subgraph antigravityPath [Antigravity]
    AgHook[Antigravity hooks.json]
    AgHook --> AgCli["tiny-engineer-antigravity"]
    AgCli --> Post
  end
  subgraph claudeCodePath [Claude Code]
    CcHook[Claude Code settings.json]
    CcHook --> CcCli["tiny-engineer-claude-code"]
    CcCli --> Post
  end
  Post --> Robot[Tiny Engineer on Wi-Fi]
```

---

## 1. REST API (any AI IDE)

Call the board directly. Works with Claude Code, Windsurf, Continue, custom plugins, shell hooks, or anything that can `POST` over HTTP.

### Main call

```bash
curl -X POST "http://tiny-engineer.local/anim?name=typing"
```

| `name` | Typical use |
|---|---|
| `typing` | Agent writing / editing / running tools |
| `reading` | Agent reading files / context |
| `thinking` | Agent reasoning / waiting on a long step |
| `ring` | Turn finished (attention ping) |
| `welcome` | Session start / greeting |
| `wakeup` | Sleep-inertia wake (eyes/head) |
| `sleep` | Force sleep (eye close + OLED off) |
| `attention` | Needs user input |
| `error` / `abort` | Failure / cancel |
| `dead` | Out of power (error line, then X X hold) |
| `none` | Idle / clear pose |

Firmware holds each pose ≥1s and keeps only the **latest** pending switch — spam-safe. Auth is optional: if you set an access token on the device, send `Authorization: Bearer <token>` (check `GET /auth` for `required`). Prefer short timeouts (e.g. 2s) and ignore network errors so the agent never stalls if the robot is offline.

### Minimal examples

**Shell**

```bash
curl -4 -sS -m 2 -X POST "http://tiny-engineer.local/anim?name=reading" >/dev/null || true
```

**JavaScript (Node 18+)**

```js
await fetch("http://tiny-engineer.local/anim?name=thinking", {
  method: "POST",
  signal: AbortSignal.timeout(2000),
}).catch(() => {});
```

**Python**

```python
import urllib.request
urllib.request.urlopen(
    urllib.request.Request(
        "http://tiny-engineer.local/anim?name=typing",
        method="POST",
    ),
    timeout=2,
)
```

Wire these into your IDE’s hook / plugin / lifecycle events (prompt submitted → `reading`, tool use → `typing`, turn end → `ring`, etc.). Mapping is yours; the robot only cares about `name`.

Health check (no motion):

```bash
curl http://tiny-engineer.local/health
```

More routes (tests, servo, web UI): [`api.md`](api.md).

---

## 2. Cursor dedicated script

For [Cursor](https://cursor.com/) only: a small Node CLI reads Cursor hook JSON on stdin, picks an animation, and POSTs `/anim`. No need to implement the event map yourself.

### Command

```bash
npx -y --package=https://github.com/jamro/tiny-engineer/archive/refs/heads/main.tar.gz tiny-engineer-cursor
```

- HTTPS **tarball** (not `github:…` SSH shorthand — that often fails in Cursor hooks with no SSH agent).
- Bin name `tiny-engineer-cursor` required after `--package=…`.
- Optional: `--url http://192.168.x.x` (default `http://tiny-engineer.local`).
- Auth: if the device has an `access_token`, set `TINY_ENGINEER_TOKEN` in the process env or a project-root `.env` file (same value). The CLI sends `Authorization: Bearer …`. No token → no header (auth disabled on device).
- `--help` for usage and event map.

### Smoke test

```bash
npx -y --package=https://github.com/jamro/tiny-engineer/archive/refs/heads/main.tar.gz tiny-engineer-cursor --help
echo '{"hook_event_name":"stop"}' | npx -y --package=https://github.com/jamro/tiny-engineer/archive/refs/heads/main.tar.gz tiny-engineer-cursor
```

### Wire into any Cursor project

In that project’s `.cursor/hooks.json`, use the same command for each anim hook. Set **`timeout` ≥ 30** (cold `npx` can exceed 2s). Full sample + event table: [`hooks.md`](hooks.md).

Inside this firmware repo you can instead run the local bin while developing the CLI:

```bash
node packages/tiny-engineer-cursor/bin/tiny-engineer-cursor.js
```

---

## 3. Antigravity CLI dedicated script

For [Google Antigravity](https://github.com/google/antigravity) (`antigravity-cli`): a lightweight Node CLI receives Antigravity lifecycle hook payloads on stdin, maps the agent lifecycle / tool calls to animations, and responds with the expected hook decision JSON while posting `/anim`.

### Event Mapping
- **`PreInvocation`** (Model thinking) → `thinking`
- **`PreToolUse`** (Reading tools: `view_file`, `grep_search`, `find_by_name`, `list_dir`, etc.) → `reading`
- **`PreToolUse`** (Writing tools: `write_to_file`, `replace_file_content`, `run_command`) → `typing`
- **`PostToolUse`** (Tool error) → `attention`
- **`Stop`** (`model_stop` / completion) → `ring` (rings the physical desk bell!)
- **`Stop`** (`error` / `aborted`) → `error` / `abort`

### Setup

Inside this firmware repository, [`.agents/hooks.json`](../.agents/hooks.json) is pre-configured. Run the local bin: `node packages/tiny-engineer-antigravity/bin/tiny-engineer-antigravity.js`. Other machines can `npx -y --package=https://github.com/jamro/tiny-engineer/archive/refs/heads/main.tar.gz tiny-engineer-antigravity` (same tarball pattern as Cursor).

To run globally across all projects on your machine, configure `~/.gemini/config/hooks.json`:

```json
{
  "tiny-engineer": {
    "PreInvocation": [
      {
        "command": "tiny-engineer-antigravity PreInvocation",
        "timeout": 3
      }
    ],
    "PreToolUse": [
      {
        "matcher": "*",
        "hooks": [
          {
            "command": "tiny-engineer-antigravity PreToolUse",
            "timeout": 3
          }
        ]
      }
    ],
    "PostToolUse": [
      {
        "matcher": "*",
        "hooks": [
          {
            "command": "tiny-engineer-antigravity PostToolUse",
            "timeout": 3
          }
        ]
      }
    ],
    "Stop": [
      {
        "command": "tiny-engineer-antigravity Stop",
        "timeout": 3
      }
    ]
  }
}
```

---

## 4. Claude Code dedicated script

For [Claude Code](https://code.claude.com/): a small Node CLI reads Claude Code hook JSON on stdin, picks an animation, and POSTs `/anim`. Same shape as the Cursor CLI — one command for every hook, no animation args.

### Event Mapping
- **`SessionStart`** (`startup`, a fresh launch) → `welcome`
- **`SessionStart`** (`resume`, `clear`, `compact`, `fork`, or no `source`) → `wakeup`
- **`SessionEnd`** → `sleep` (skipped for `clear` and `resume`, where the next `SessionStart` wakes the robot)
- **`UserPromptSubmit`** → `reading`
- **`PreToolUse`** (Reading tools: `Read`, `Grep`, `Glob`, `WebFetch`, `WebSearch`) → `reading`
- **`PreToolUse`** (Writing tools: `Bash`, `PowerShell`, `Edit`, `Write`, `NotebookEdit`) → `typing`
- **`SubagentStart`** → `thinking`
- **`PostToolBatch`** (tool results go back to the model) → `thinking`
- **`PostToolUseFailure`** (a tool call failed) → `error`
- **`PreCompact`** → `thinking`
- **`PermissionRequest`** → `attention`
- **`PermissionDenied`** (auto mode denied a tool call) → `abort`
- **`Notification`** (permission prompt, or waiting for input) → `attention`
- **`Stop`** (turn finished) → `ring` (rings the physical desk bell!)
- **`StopFailure`** → `error`

To change the map, edit [`packages/tiny-engineer-claude-code/src/map.js`](../packages/tiny-engineer-claude-code/src/map.js).

### Setup

Inside this firmware repository, [`.claude/settings.json`](../.claude/settings.json) is pre-configured: open the repo in Claude Code (Node.js 18+) and the hooks run `node packages/tiny-engineer-claude-code/bin/tiny-engineer-claude-code.js`.

- Every hook is `"async": true`, so Claude Code runs it in the background — an offline robot never stalls a tool call on the 2s HTTP timeout.
- Robot address: `TINY_ENGINEER_URL` or `--url http://192.168.x.x` (default `http://tiny-engineer.local`).
- Auth: if the device has an `access_token`, set `TINY_ENGINEER_TOKEN` in the process env or a project-root `.env` file. The CLI sends `Authorization: Bearer …`. No token → no header (auth disabled on device). When the token comes from the process env, a `TINY_ENGINEER_URL` in the project `.env` is ignored, so a project can't redirect your token; set the URL in the env or with `--url`.
- The CLI never writes to stdout in hook mode — Claude Code adds `SessionStart` / `UserPromptSubmit` hook stdout to the model's context.
- If a hook never fires, run `/hooks` inside Claude Code to confirm the project settings loaded.

To use it in every project, copy the `hooks` block into `~/.claude/settings.json` and replace `$CLAUDE_PROJECT_DIR/packages/…` with the absolute path to this repo's bin.

### Smoke test

```bash
node packages/tiny-engineer-claude-code/bin/tiny-engineer-claude-code.js --help
echo '{"hook_event_name":"Stop"}' | node packages/tiny-engineer-claude-code/bin/tiny-engineer-claude-code.js
```

---

## Which to choose?

- **Building for one IDE / custom agent** → REST. One `POST`, zero Node dependency.
- **Using Cursor and want zero mapping code** → Cursor CLI + hooks.
- **Using Antigravity CLI** → Antigravity CLI + hooks.
- **Using Claude Code** → Claude Code CLI + hooks.
- **All four** are fine together: the CLIs are thin clients of the same `/anim` API.

Prerequisites for any path: flash firmware, join 2.4 GHz Wi-Fi, confirm `http://tiny-engineer.local/health` (or the OLED IP) responds.

---

## Optional extras

Same `POST /anim` API; not part of the four paths above. On macOS you can run a small host helper that POSTs `sleep` / `wakeup` when the screen locks or unlocks: [`macos-lock-unlock.md`](macos-lock-unlock.md). The robot does not need it.

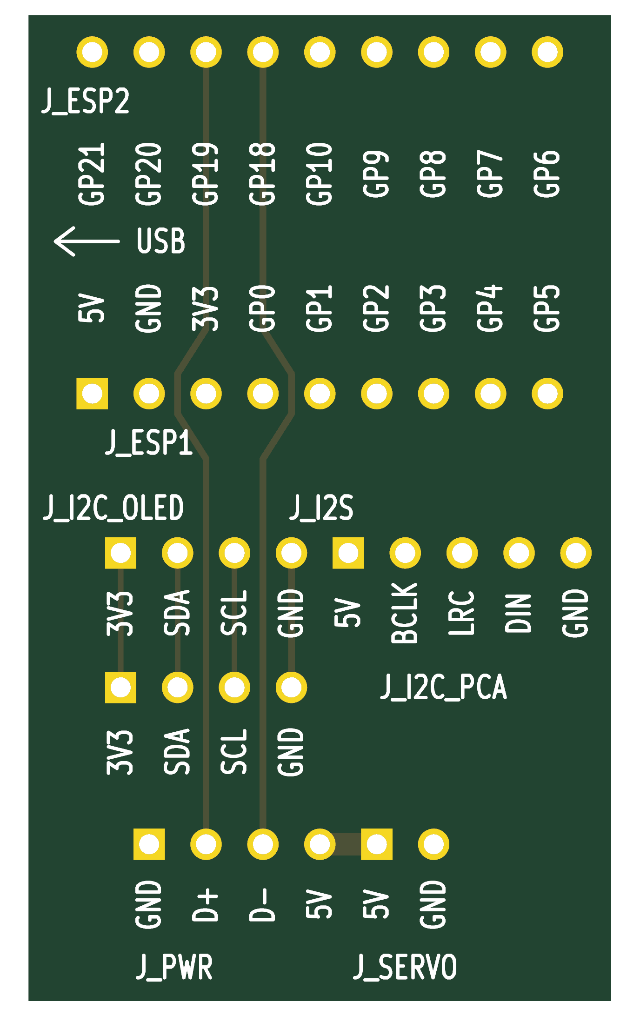
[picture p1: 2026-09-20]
hardware/boards/compact-carrier-board/carrier-board-render.png

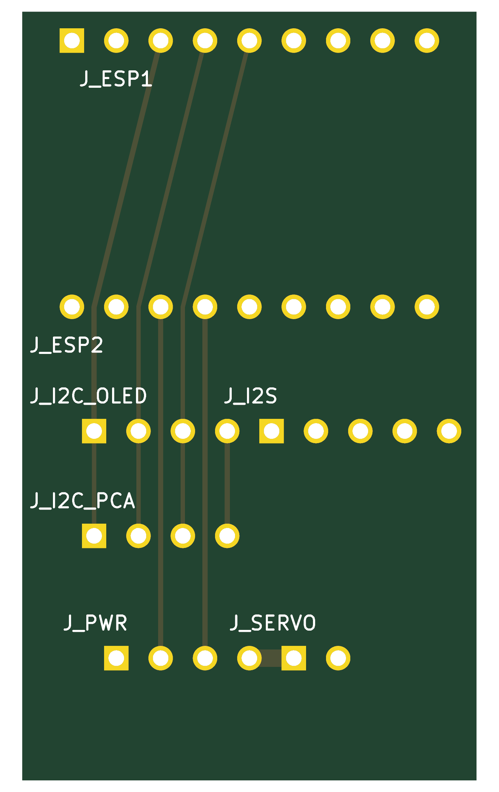
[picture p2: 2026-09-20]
hardware/boards/compact-carrier-board-pinside/carrier-board-render.png

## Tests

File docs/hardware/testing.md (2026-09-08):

# Hardware testing

Firmware is [`src/main.cpp`](../../src/main.cpp). Boot **inits** hardware and starts HTTP. Demos (OLED, tones, servo sweep) run on demand via REST. Helpers:

- [`src/hardware/rgb.cpp`](../../src/hardware/rgb.cpp)
- [`src/display/oled.cpp`](../../src/display/oled.cpp) (init/boot/test: `oled_init.cpp`, `oled_boot.cpp`, `oled_test.cpp`)
- [`src/network/wifi_connect.cpp`](../../src/network/wifi_connect.cpp)
- [`src/audio/audio.cpp`](../../src/audio/audio.cpp)
- [`src/hardware/pca9685_servos.cpp`](../../src/hardware/pca9685_servos.cpp)
- [`src/http/http_server.cpp`](../../src/http/http_server.cpp), [`src/http/test_handlers.cpp`](../../src/http/test_handlers.cpp)

Constants: [`include/pins.h`](../../include/pins.h). Wi-Fi credentials are saved in NVS and configured only in setup AP mode (first boot, or after factory reset + power-cycle).

Build/flash: project root README (`pio run`, `pio run -t upload`, serial 115200). Physical board is **Waveshare ESP32-C3-Zero**; PlatformIO env name is `esp32-c3-devkitm-1`.

## What boot covers

| Subsystem | How |
| --- | --- |
| Built-in WS2812 | Green ready (GPIO10) |
| I2C init | `Wire.begin` on GPIO0/GPIO1 |
| PCA9685 | Probe `0x40` early; park neutral; optional OE on GP5 |
| OLED | Probe `0x3C`, init (optional) |
| Wi-Fi | STA connect from saved NVS credentials, or setup AP `TinyEngineer-XXXX` when unset/failed; mDNS `{hostname}.local` after STA connect |
| MAX98357A / I2S | `I2S.begin` 44.1 kHz 16-bit stereo |
| Servos | Smooth move to mid (or sleep pose) at 35°/s |
| HTTP | Port 80 if Wi-Fi connected |
| Success | Dim green RGB during init; then animation LED (see below) |
| Fatal init failure | Red blink code on the WS2812 (see below) |

## Boot-failure blink codes

A fatal init failure halts boot and blinks the onboard WS2812 red. The number of
flashes before the long gap identifies the subsystem:

| Blinks | Meaning |
| --- | --- |
| 1 | PCA9685 not found on I2C `0x40` |
| 2 | MAX98357A / I2S init failed |

Each flash is 300 ms on, 300 ms off; the gap between repeats is 3 s, so the start of a
cycle is easy to find. Serial carries the same message, but the blink code is readable
with no cable attached — and with `serial_log` off (the default) the serial line is
silent, which makes the LED the only signal a first-boot board gives you.

## Expected boot sequence

1. Serial banner `TINY ENGINEER`
2. `Starting I2C` / `SDA = GP0` / `SCL = GP1`
3. `Checking PCA9685 at 0x40...` → **must** succeed; all channels parked at mid
4. `Checking OLED at 0x3C...` → found or `ERROR: OLED not found` (continues)
5. Settings load from NVS (`loading` = `progress` or `sleep_inertia`)
6. **Progress loading (default):** OLED progress steps (Display → WiFi → Servos → Audio → Storage → Ready), then large full-width IP (or `No IP`) for 3 s, then idle eyes
7. **Sleep inertia loading:** closed eyes during init; smooth move to sleep pose if `welcome` is on; slow eye open + blinks (~5.5 s). Head/neck wave only if `welcome` is on; otherwise eyes only
8. `WIFI SETUP` on serial — connect OK + IP, open setup AP, or saved credentials failed (setup AP for reconfiguration)
9. `Starting MAX98357A` → `I2S OK`
10. `Centering servos` — smooth move to per-channel mid (progress path only; skipped if sleep pose already applied)
11. `ROBOT READY`
12. RGB fades to white over 1 s if `welcome` runs (Wi-Fi OK and setting enabled), or fades off if idle
13. If Wi-Fi OK: `HTTP: http://<ip>/`, `HTTP: http://tiny-engineer.local/`, and `/health` URLs on serial
14. If setup AP active: `HTTP setup: http://192.168.4.1/config` on serial; OLED rotates setup instructions

`loop()` pumps the HTTP server and updates animation RGB fades. No audio/OLED/servo/LED demos until a POST.

## Animation RGB

During normal operation the onboard WS2812 tracks the active animation (not boot green):

| Animation | LED |
| --- | --- |
| `typing`, `reading`, `thinking`, `welcome`, `ring`, `wakeup` | White |
| `attention`, `error`, `dead` | Pulsing red (10%↔100%, 1.5 s cycle) |
| `abort` | Solid red |
| `none`, `sleep` | Off |

State changes fade over **1 s** (see [`docs/api.md`](../api.md#rgb-led)). Trigger via `POST /anim?name=…` or Cursor hooks.

OLED shows matching status strings when the panel is present (progress loading: WiFi step labels; sleep inertia: eyes only).

## HTTP tests

API reference: [`docs/api.md`](../api.md).

Base URL is the board IP or `http://tiny-engineer.local` (2.4 GHz STA). Tests have side effects — use **POST**, not GET.

```bash
# Health
curl http://tiny-engineer.local/health

# Tones 500 / 700 / 1000 Hz
curl -X POST http://tiny-engineer.local/test/audio

# OLED title / HELLO / X in a box
curl -X POST http://tiny-engineer.local/test/screen

# Servos 90 → 105 → 75 → 90 (channels 0–4)
curl -X POST http://tiny-engineer.local/test/movement

# Onboard WS2812 R → G → B → white → off, then back to current animation LED
curl -X POST http://tiny-engineer.local/test/led

# One servo smooth move to angle (~40°/s; index 0–4, angle 0–180)
curl -X POST "http://tiny-engineer.local/test/servo?index=0&angle=90"
```

| Method | Path | Body |
| --- | --- | --- |
| `GET` | `/` | HTML endpoint index |
| `GET` | `/auth` | Auth status (`ok`, `required`) — always public |
| `GET` | `/health` | Health JSON (`ok`, `uptime_ms`, `free_heap`, `heap_size`, `cpu_temp_c`, `wifi`, `oled`) |
| `GET` | `/settings` | Persistent settings (`sleep_timeout`, `hostname`, `volume`, `welcome`, `serial_log`, `continuous_timeout`, `loading`, `access_token_set`, `wifi_configured`, `wifi_ssid`, `wifi_password_set`) |
| `POST` | `/settings?...&wifi_ssid=&wifi_password=` | Update NVS settings; WiFi params setup-AP-only and tested before save; `reboot_required` if hostname changed |
| `POST` | `/settings/reset` | Factory reset all settings to defaults (clears WiFi); power-cycle to reopen setup AP |
| `POST` | `/test/audio` | `{"ok":true,"test":"audio"}` after `runSoundTest()` |
| `POST` | `/test/screen` | `{"ok":true,"test":"screen"}` after `runOledTest()` |
| `POST` | `/test/movement` | `{"ok":true,"test":"movement"}` after `runServoTest()` |
| `POST` | `/test/led` | `{"ok":true,"test":"led"}` after `runRgbTest()` |
| `POST` | `/test/servo?index=&angle=` | `{"ok":true,"test":"servo","index":N,"angle":A}` after `moveServoSmooth()` |

GET on a test path returns `405`. Bad `/test/servo` or `/settings` params return `400`. Missing/wrong Bearer when auth enabled returns `401`. Control APIs return `503` when WiFi credentials are not saved. Unknown path returns `404`. JSON `Content-Type`. Handlers block until the test finishes; the OLED returns to `ROBOT READY` after.

HTTP runs on STA when connected, or on setup AP at `192.168.4.1` during provisioning.

## Failures

| Serial / OLED | Meaning | Check |
| --- | --- | --- |
| OLED `ERROR: OLED not found` then rest of boot runs | Nothing ACK’d at `0x3C` | OLED **VCC=3V3**, GND, SDA=GP0, **SCK**=GP1, common ground, address jumper still 0x3C |
| OLED found but `ERROR: OLED initialization failed` | ACK then `display.begin` failed | Wiring/power glitch, wrong size module, I2C noise |
| OLED shows `Join this WiFi` / AP name, then `Then open` / `192.168.4.1` | Setup AP mode active | Connect to the shown AP, open `http://192.168.4.1/config`, enter home WiFi credentials |
| OLED `WiFi failed` then setup AP | Saved STA credentials failed | Join setup AP, open `http://192.168.4.1/config`, enter home WiFi again |
| `ERROR: PCA9685 not found` + red RGB + **hang** | Nothing ACK’d at `0x40` | PCA9685 **VCC=3V3** (not V+), GND, SDA/SCL, I2C address pads, +5V not required for the ACK but needed later for motion |
| `ERROR: I2S initialization failed` + red RGB + **hang** | `I2S.begin` failed | GPIO2/3/4 not shorted to 5V/GND; pin constants; USB CDC still alive so you can read the line |
| I2S OK but `POST /test/audio` is silent | Amp or speaker | MAX98357A **Vin**=USB 5V, GND, GP2/3/4 → BCLK/LRC/DIN, speaker on **SPK+ / SPK-** (not on the PNG, not GND) |
| Servos silent / twitch / ESP32 resets during `POST /test/movement` | Power or SIG | **V+** is +5V, SIG on ch 0–4, **common GND**, supply current — see [power.md](power.md) |
| RGB never goes green | GPIO10 LED path | Board is C3-Zero (LED on GPIO10). Do not expect an external NeoPixel |

OLED absence and Wi-Fi failure are **soft** fails. PCA9685 and I2S failures **halt** in `while (true)`.

## Power during the servo test

All five servos move together on `POST /test/movement`. A weak USB port often dies **here**. If the serial port drops exactly when that POST runs: treat as brownout, not a PWM bug. Boot only parks at 90°, which is much lighter.

## What this test does not prove

- That tuned mechanical limits match a particular physical build (start from `SERVO_SPECS`; adjust after assembly)
- BLE (out of scope)
- Speaker power rating vs max amp output
- I2C at high speed

Related: [pinout.md](pinout.md), [wiring.md](wiring.md), [servos.md](servos.md).

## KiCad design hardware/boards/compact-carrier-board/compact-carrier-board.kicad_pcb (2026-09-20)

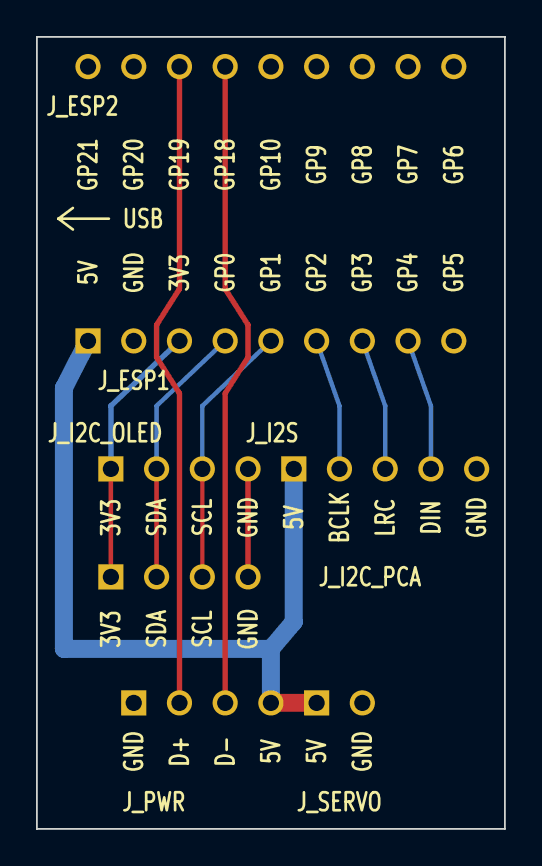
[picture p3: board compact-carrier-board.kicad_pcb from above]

Board: 2 copper layers, 26.0 x 44.0 mm, 7 parts (0 on the bottom side), 10 nets.

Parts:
J_ESP1: Kinghelm KH-2.54FH-1X9P-H3.5; J_ESP1
J_ESP2: Kinghelm KH-2.54FH-1X9P-H3.5; J_ESP2
J_I2C_OLED: J_I2C_OLED
J_I2C_PCA: J_I2C_PCA
J_I2S: J_I2S
J_PWR: J_PWR
J_SERVO: J_SERVO

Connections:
3V3: J_ESP1.3, J_I2C_OLED.1, J_I2C_PCA.1
5V: J_ESP1.1, J_I2S.1, J_PWR.4, J_SERVO.1
BCLK: J_ESP1.6, J_I2S.2
DIN: J_ESP1.8, J_I2S.4
GND: J_ESP1.2, J_I2C_OLED.4, J_I2C_PCA.4, J_I2S.5, J_PWR.1, J_SERVO.2
LRCLK: J_ESP1.7, J_I2S.3
SCL: J_ESP1.5, J_I2C_OLED.3, J_I2C_PCA.3
SDA: J_ESP1.4, J_I2C_OLED.2, J_I2C_PCA.2
USB_DM: J_ESP2.15, J_PWR.3
USB_DP: J_ESP2.16, J_PWR.2

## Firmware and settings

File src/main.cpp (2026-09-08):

#include <Arduino.h>
#include <Wire.h>
#include <ESP_I2S.h>

#include "pins.h"
#include "hardware/rgb.h"
#include "hardware/chip_temp.h"
#include "display/oled.h"
#include "audio/audio.h"
#include "animation.h"
#include "animation/constants.h"
#include "animation/util.h"
#include "hardware/pca9685_servos.h"
#include "hardware/servo_wrapper.h"
#include "network/wifi_connect.h"
#include "http/http_server.h"
#include "settings.h"
#include "serial_log.h"
#include "sleep.h"
#include "boot/boot_loading.h"

namespace {

constexpr int kBootSteps = 6;

}  // namespace

void setup() {
  initServoOutputPin();

  Serial.begin(115200);
  Serial.setTxTimeoutMs(0);
  delay(1000);

  initSettings();

  initChipTemp();

  serialLogPrintln();
  serialLogPrintln("==========================");
  serialLogPrintln("TINY ENGINEER");
  serialLogPrintln("==========================");

  setRgb(0, 32, 0);

  serialLogPrintln();
  serialLogPrintln("Starting I2C");
  serialLogPrintln("SDA = GP0");
  serialLogPrintln("SCL = GP1");

  Wire.begin(
    I2C_SDA,
    I2C_SCL
  );

  delay(100);

  initPca9685();

  initOled();

  const bool sleepServos = bootSleepInertiaUsesServos();

  if (bootLoadingIsProgress()) {
    bootShowProgress(1, kBootSteps, "Display");
  } else {
    bootBeginSleepingFace();
  }

  if (sleepServos) {
    bootSnapSleepPose();
  }

  bootShowProgress(2, kBootSteps, "WiFi...");
  runWifiSetup();
  bootShowProgress(
    2,
    kBootSteps,
    wifiConnected() ? "WiFi OK" :
    wifiProvisioningMode() ? "WiFi setup" : "WiFi failed"
  );

  bootShowProgress(3, kBootSteps, "Servos");

  serialLogPrintln();
  serialLogPrintln(
    "Starting MAX98357A"
  );

  I2S.setPins(
    I2S_BCLK,
    I2S_LRC,
    I2S_DIN
  );

  if (!I2S.begin(
        I2S_MODE_STD,
        SAMPLE_RATE,
        I2S_DATA_BIT_WIDTH_16BIT,
        I2S_SLOT_MODE_STEREO
      )) {
    serialLogPrintln(
      "ERROR: I2S initialization failed"
    );

    showOledText(
      "I2S ERROR",
      "Init failed"
    );

#ifdef ALLOW_MISSING_HARDWARE
    serialLogPrintln(
      "ALLOW_MISSING_HARDWARE: continuing without audio"
    );
#else
    haltWithRgbCode(RGB_CODE_I2S);
#endif
  } else {
    serialLogPrintln("I2S OK");
  }

  bootShowProgress(4, kBootSteps, "Audio");

  initAudioStorage();
  bootShowProgress(5, kBootSteps, "Storage");

  if (!sleepServos) {
    serialLogPrintln("Centering servos");
    centerAllServos();
  }

  if (bootLoadingIsProgress()) {
    bootShowProgress(kBootSteps, kBootSteps, "Ready");
    if (wifiProvisioningMode()) {
      showProvisioningOled("Join this WiFi", wifiApSsid());
    } else {
      showBootIp(wifiConnected() ? wifiIpText() : "");
      delay(3000);
      showIdleScreen();
    }
  } else {
    bootRunSleepInertia();
    if (wifiProvisioningMode()) {
      showProvisioningOled("Join this WiFi", wifiApSsid());
    }
  }

  serialLogPrintln();
  serialLogPrintln("==========================");
  serialLogPrintln("ROBOT READY");
  serialLogPrintln("==========================");

  if (wifiConnected() && settingsWelcomeEnabled()) {
    setAnimation(AnimationId::Welcome);
  } else if (wifiConnected() && !settingsWelcomeEnabled()) {
    anim::parkHands(anim::TRANSITION_HAND_SPEED_DEG_S);
  } else if (wifiProvisioningMode()) {
    setRgb(0, 0, 64);
  } else {
    setRgbForAnimation(AnimationId::None, millis());
  }

  if (wifiConnected() || wifiProvisioningMode()) {
    startHttpServer();
  }
  initSleep();
}

void loop() {
  const uint32_t now = millis();
  pollWifi();
  pollHttpServer();
  updateProvisioningOled(now);
  updateAnimation();
  // After HTTP/anim so idle timestamp from this frame is not compared to a stale `now`.
  updateSleep(millis());
  updateRgb(now);
}

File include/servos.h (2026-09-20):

#pragma once

// =====================================================
// SERVO IDENTITY + LIMITS
// =====================================================

constexpr int SERVO_HEAD       = 0;
constexpr int SERVO_NECK       = 1;
constexpr int SERVO_HAND_LEFT  = 2;
constexpr int SERVO_HAND_RIGHT = 3;
constexpr int SERVO_BODY       = 4;

constexpr int SERVO_COUNT = 5;

struct ServoSpec {
  const char* name;
  int channel;
  float min;
  float max;
};

// SERVO_* above are ARRAY INDICES, not PCA9685 outputs: they index SERVO_SPECS,
// g_servos[] and the saved min/max blob in NVS. The physical output is the
// `channel` field below, which is the only value that reaches pwm.setPWM().
// Keep the two apart - renumbering the constants desynchronises the table,
// the runtime servos and the stored calibration, while `channel` is free to
// be any PCA9685 output 0-15.
constexpr ServoSpec SERVO_SPECS[SERVO_COUNT] = {
  //           channel as wired on this robot
  {"HEAD",       4, 50.0f, 130.0f},
  {"NECK",       0, 30.0f, 150.0f},
  {"HAND_LEFT",  3, 40.0f, 110.0f},
  {"HAND_RIGHT", 1, 60.0f, 130.0f},
  {"BODY",       2, 36.0f,  89.0f},
};

constexpr float servoMid(const ServoSpec& spec) {
  return (spec.min + spec.max) * 0.5f;
}

// Pose space: -1 = saved min, 0 = mid, +1 = saved max.
inline float servoSaturateNorm(float n) {
  if (n < -1.0f) {
    return -1.0f;
  }
  if (n > 1.0f) {
    return 1.0f;
  }
  return n;
}

inline float servoNormToDeg(float n, float savedMin, float savedMax) {
  n = servoSaturateNorm(n);
  return (savedMin + savedMax) * 0.5f + n * (savedMax - savedMin) * 0.5f;
}

inline float servoDegToNorm(float deg, float savedMin, float savedMax) {
  const float span = savedMax - savedMin;
  if (span <= 0.0f) {
    return 0.0f;
  }
  return servoSaturateNorm(2.0f * (deg - savedMin) / span - 1.0f);
}

// Max commanded slew rate for all smooth moves
constexpr float SERVO_MAX_SPEED_DEG_S = 140.0f;

// Setup-wizard calibration moves (horn 90° and per-joint sweeps)
constexpr float SERVO_CALIB_SPEED_DEG_S = 25.0f;

// ~half a PCA9685 count at 800-2200 us over 0-180 deg
constexpr float SERVO_ANGLE_DEADBAND_DEG = 0.32f;

// Approximate angular spacing of one PWM count
constexpr float SERVO_PWM_STEP_DEG = 0.63f;

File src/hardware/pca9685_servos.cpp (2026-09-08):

#include <Arduino.h>

#include "pins.h"
#include "servos.h"
#include "display/oled.h"
#include "hardware/rgb.h"
#include "hardware/servo_wrapper.h"
#include "hardware/pca9685_servos.h"
#include "serial_log.h"

bool pca9685Connected() {
  return i2cDeviceConnected(PCA9685_ADDRESS);
}

void initPca9685() {
  serialLogPrintln();
  serialLogPrintln("Checking PCA9685 at 0x40...");

  if (!pca9685Connected()) {
    serialLogPrintln("ERROR: PCA9685 not found");

    showOledText(
      "PCA9685 ERROR",
      "Not found"
    );

#ifdef ALLOW_MISSING_HARDWARE
    serialLogPrintln(
      "ALLOW_MISSING_HARDWARE: continuing without servos"
    );

    // Still init the driver. Adafruit_PWMServoDriver::begin() allocates i2c_dev
    // before it probes, and every later setPWM() dereferences that pointer.
    // Skipping begin() leaves it NULL and the first servo write panics with a
    // load access fault at 0x0c.
    initServoPwmDriver();

    return;
#else
    haltWithRgbCode(RGB_CODE_PCA9685);
#endif
  }

  serialLogPrintln("PCA9685 found");

  initServoPwmDriver();
}

bool moveServoSmooth(int index, float toAngle) {
  if (index < 0 || index >= SERVO_COUNT) {
    return false;
  }

  return servoAt(index).moveTo(toAngle);
}

void centerAllServos() {
  serialLogPrintln("Centering servos to mid (min+max)/2");

  float targets[SERVO_COUNT];

  for (int servo = 0; servo < SERVO_COUNT; servo++) {
    targets[servo] = servoMid(SERVO_SPECS[servo]);
  }

  servoMoveAllSmoothTo(targets);
}

void runServoTest() {
  constexpr int TOTAL_STEPS = 4;

  serialLogPrintln();
  serialLogPrintln("==========================");
  serialLogPrintln("SERVO TEST - HEAD/NECK/HANDS/BODY");
  serialLogPrintln("==========================");

  serialLogPrintln(
    "1. All servos -> 90 deg"
  );

  showServoProgress(
    1,
    TOTAL_STEPS,
    "ALL -> 90"
  );

  servoMoveAllSmooth(
    SERVO_CENTER
  );

  delay(1000);

  serialLogPrintln(
    "2. All servos: 90 -> 105 deg"
  );

  showServoProgress(
    2,
    TOTAL_STEPS,
    "90 -> 105"
  );

  servoMoveAllSmooth(
    SERVO_HIGH
  );

  serialLogPrintln(
    "3. All servos: 105 -> 75 deg"
  );

  showServoProgress(
    3,
    TOTAL_STEPS,
    "105 -> 75"
  );

  servoMoveAllSmooth(
    SERVO_LOW
  );

  serialLogPrintln(
    "4. All servos: 75 -> 90 deg"
  );

  showServoProgress(
    4,
    TOTAL_STEPS,
    "75 -> 90"
  );

  servoMoveAllSmooth(
    SERVO_CENTER
  );

  showServoTestFinished();

  serialLogPrintln(
    "All 5 servos test finished"
  );

  delay(1000);
}

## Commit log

2026-09-08 feat(rgb): identify the failed subsystem with a red blink code
    Both fatal init failures halted with the same solid red, so the LED said
    "boot failed" but not where.
    That matters because the two halts sit before Wi-Fi: serial logging is off
    by default, a board with unwritten NVS falls back to that default, and the
    HTTP settings API that could turn logging on is unreachable behind the halt.
    Such a board stops, prints nothing about why, and cannot be told to start
    printing -- the LED is the only signal it gives.
    Route both halts through haltWithRgbCode(), which blinks red N times, pauses,
    and repeats. 1 = PCA9685 not found, 2 = I2S init failed, as named constants
    in rgb.h.
    The 3000 ms gap is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
    [main.cpp, pca9685_servos.cpp]
2026-09-08 fix(rgb): this C3-Zero unit's WS2812 is RGB-ordered, not GRB
    LOCAL DEVIATION -- do not push upstream as-is. See jamro/tiny-engineer#22.
    setRgb(64, 0, 0) -- an unambiguous request for red -- rendered as bright
    green on this board. Every non-grey colour came out with R and G transposed.
    Discriminated from the alternatives by driving BLUE, which is the last byte
    in both GRB and RGB orderings and therefore order-independent: blue rendered
    correctly on GPIO10, ruling out a wrong pin and a dead LED and leaving byte
    order as the only remaining explanation.
    Upstream asserts GRB and presumably verified that on their own unit. WS2812
    clones genuinely ship in both orderings under the same part numbe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
2026-09-08 chore(bench): ALLOW_MISSING_HARDWARE lets boot reach Wi-Fi with nothing wired
    BENCH ONLY -- remove this commit once the PCA9685 and MAX98357A are wired.
    Not suitable for upstream in this form.
    Both fatal init failures halt before runWifiSetup(), so a board with no I2C
    peripherals never raises its setup AP and cannot be reached at all. This
    build flag turns both halts into warnings so the web UI comes up on a bare
    module, which is what made the rest of the bring-up possible.
    Two things this deliberately does NOT do:
    The PCA9685 bypass still calls initServoPwmDriver(). An earlier version
    returned early to skip the halt and skipped begin() with it -- but
    Adafruit_PWMServoDriver::begin() is w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
    [main.cpp, pca9685_servos.cpp]
2026-09-08 chore(bench): default serial logging ON so a first-boot halt can explain itself
    BENCH ONLY -- revert before any upstream PR.
    Every diagnostic routes through the gated serialLogPrintln(), and the gate
    reads a value from NVS. On a first boot NVS has never been written
    (nvs_open failed: NOT_FOUND), so this compiled default applies -- and it was
    false. A board that halts during init therefore prints NOTHING about why, and
    the only way to turn logging on is the HTTP settings API, which sits behind
    the very halt you are trying to diagnose.
    That combination is what made the original "no setup AP" fault look like a
    dead board rather than a deliberate halt: the one line that did escape was a
    Prefer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
2026-09-08 feat(claude): pose the robot from Claude Code hooks
    Upstream ships a turnkey integration for Cursor only (tiny-engineer-cursor
    CLI + .cursor/hooks.json). docs/integration.md documents the REST contract
    and names Claude Code, but states "Mapping is yours" -- so this wiring is
    ours.
    .claude/hooks/pose.sh POSTs /anim?name=<anim> and appends to a local log;
    .claude/settings.json maps 11 hook commands across 6 event types.
    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
2026-09-20 servos: map SERVO_SPECS channels to the harness as actually wired
    The servo harnesses were attached without tracking which body part went to
    which PCA9685 output. Identified each by driving one channel at a time:
    neck 0, right hand 1, body 2, left hand 3, head 4.
    Only the `channel` field moves. The SERVO_* constants stay 0-4 because they
    are ARRAY INDICES - they index SERVO_SPECS, g_servos[] and the saved min/max
    blob in NVS. Renumbering them would desynchronise the table, the runtime
    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
2026-09-20 servos: default ranges to this robot's measured calibration
    The stock SERVO_SPECS ranges describe the reference build; this one has a
    remounted neck horn and its own linkage geometry, so the committed defaults
    described a robot that does not exist. Sync them to the values arrived at
    through the setup-AP wizard:
    head 60-130 -> 50-130
    neck 40-130 -> 30-150 (wizard recorded 0-180; narrowed deliberately)
    left hand 45-135 -> 40-110
    right hand 35-125 -> 60-130
    body 40-130 -> 36-89 (mid 62.5, verified square)
    The neck is the one judgement call. Nothing binds mechanically in either
    direction, so the wizard saved the full 0-180 electrical span; that maps
    animation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
    [servos.h]
2026-09-20 hardware: drop the superseded flat carrier-board tree
    The merge left two copies of the board: hardware/compact-carrier-board/ from
    main's pre-rename layout, and hardware/boards/compact-carrier-board/ which
    follows upstream's boards/<name>/ convention. Git merged both silently
    because it sees unrelated paths.
    The flat one is superseded on every count - it carries the MIRRORED socket
    artwork this branch fixed, and it commits generated outputs the board README
    says not to keep in-tree: BOM.csv, CPL.csv and carrier-fab-v3.zip, the
    latter being the defective _Y3 upload with seven undersized J_ESP2 holes.
    Nothing outside the directory referenced it: a grep for
    hardware/compact-carrier-board, car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
    [BOM.csv, carrier.kicad_pcb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]
